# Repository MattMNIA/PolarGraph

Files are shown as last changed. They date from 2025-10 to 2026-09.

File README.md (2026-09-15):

# PHINEAS

**P**lotting **H**ardware for **I**nteractive **N**otation, **E**rasing, **A**nd **S**ketching — a
belt-driven polargraph that draws on a standard classroom whiteboard. Drop an image into the
browser, place it on a scale drawing of your board, and the machine draws it with a dry-erase
marker.

<p align="center">
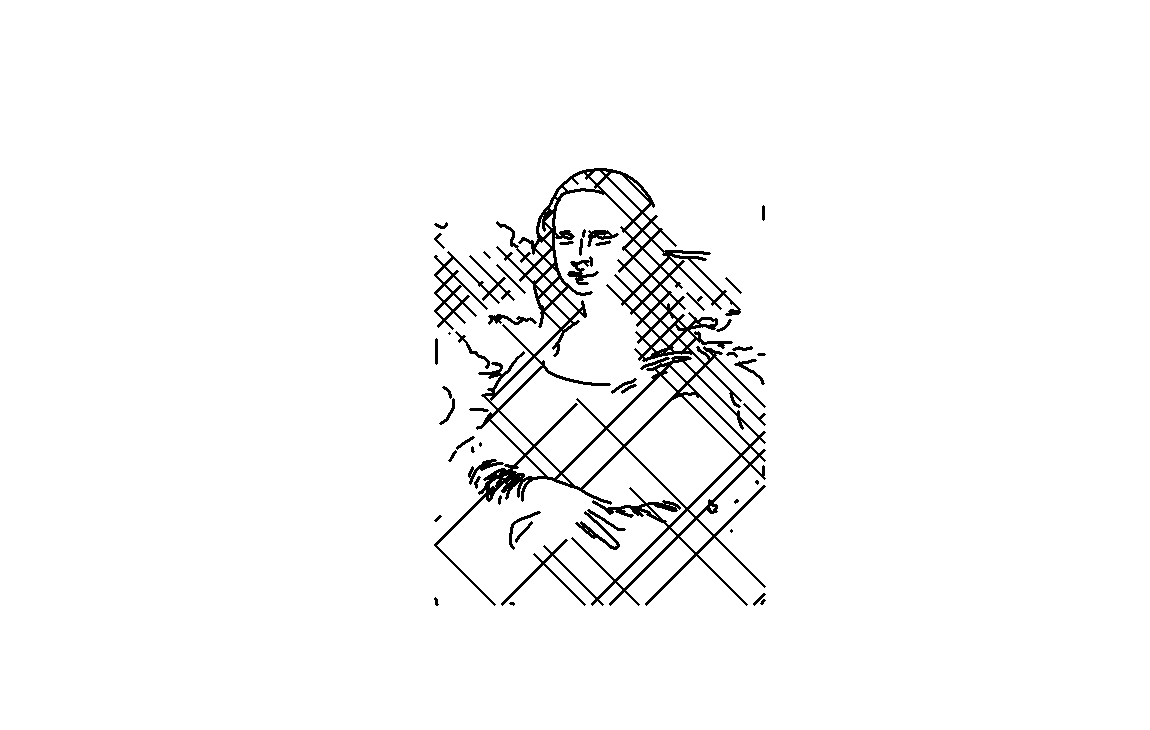
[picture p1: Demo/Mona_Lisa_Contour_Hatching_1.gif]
Simulated pen path for a contour + hatch render of the Mona Lisa
  
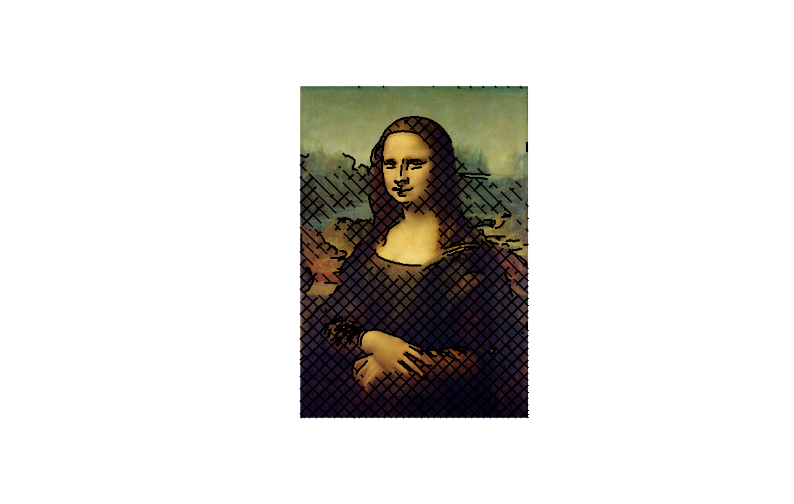
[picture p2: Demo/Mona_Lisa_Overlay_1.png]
Finished drawing on the whiteboard
  
</p>

A gondola hangs from two GT2 belts driven by stepper motors in the top corners of the board. Its
position is set entirely by the two belt lengths, so moving the pen means solving for those two
lengths and stepping both motors together. A hobby servo on the gondola lifts the marker off the
board between strokes.

## How it works

```
image ──▶ OpenCV                ──▶ path planner            ──▶ Flask API ──▶ ESP32 ──▶ steppers
          contours / hatching       ordering, pen-up/down        batches       inverse    + pen servo
          /  dark fill              interpolation, merging       of 200 pts    kinematics
```

1. **Trace.** `polargraph/image_processing.py` reduces the image to pen strokes, in one of three
   modes: `contour` (edge outlines with centerline extraction), `hatch` (outlines plus angled
   hatching whose density follows image brightness), or `fill` (outlines plus solid fill of dark
   regions).
2. **Plan.** `polargraph/path_planner.py` splits and merges contours where they nearly touch,
   orders them nearest-neighbour to cut travel, then interpolates every stroke to a fixed step
   size and marks each point pen-up or pen-down.
3. **Preview.** The React client renders the planned path over a scale drawing of the board, so
   you can see the result and the estimated draw time before committing a marker to it.
4. **Stream.** `polargraph/path_sender.py` pushes the path to the ESP32 in 200-point batches on a
   background thread, keeping the controller's queue full without blocking the API. Progress,
   pause, resume, and cancel are all polled over HTTP.
5. **Draw.** The firmware converts each point to a pair of belt lengths, steps both motors in
   coordinated fashion, and drives the pen servo. It parks the gondola when the job finishes.

## Layout

| Path | What's in it |
|---|---|
| `client/` | React + Tailwind front end: board layout editor, drawing-method controls, live job monitor, motor jog/test pages. |
| `visualization/` | Flask API and the `polargraph` Python package — kinematics, image processing, path planning, and the batched path sender. |
| `visualization/examples/` | Standalone scripts: shapes, calibration squares, timing tests, a diagnostic suite. |
| `visualization/tests/` | Unit tests for the kinematics and path planning. |
| `firmware/` | ESP32 Arduino sketch (WebServer + TMCStepper + ESP32Servo) and two PowerShell helpers for poking the controller by hand. |
| `Demo/` | Sample output. |

CAD (`.3mf` printable parts), the KiCad project for the driver board, and the bill of materials
live outside the repo — ask if you want them.

## Running it

**Backend** (Python 3.8+):

```bash
cd visualization
python -m venv .venv && .venv/Scripts/activate   # source .venv/bin/activate on macOS/Linux
pip install -r requirements.txt
python app.py                                    # serves on :8001
```

**Front end** (Node 18+):

```bash
cd client
npm install
npm start                                        # dev server on :3000, talking to the API on :8001
```

`npm run build` emits into `client/build/`, which `app.py` serves directly — so a production run is
just the Flask process.

**Firmware** (Arduino IDE or `arduino-cli`, ESP32 board support installed):

1. Copy `firmware/polargraph_firmware/secrets.example.h` to `secrets.h` in the same folder and fill
   in your WiFi credentials. That file is gitignored.
2. Check the machine geometry constants at the top of `polargraph_firmware.ino` —
   `BOARD_WIDTH_MM`, `BOARD_HEIGHT_MM`, `SPOOL_DIAMETER_MM`, `MICROSTEPS`, and the pen servo
   angles all have to match your build.
3. Flash it. The sketch prints its IP on the serial console; paste that into the client's
   controller URL field.

Libraries used by the sketch: `ArduinoJson`, `TMCStepper`, `ESP32Servo`.

## API

Flask (`visualization/app.py`):

| Endpoint | Purpose |
|---|---|
| `POST /api/visualize` | Plan a drawing from a board layout; returns the preview, path stats, and optionally starts streaming. |
| `POST /api/animation` | Render an animated preview of the planned path. |
| `POST /api/send-path` | Queue a path for transmission; returns a job id immediately. |
| `GET /api/send-path/status` | Poll progress, totals, and errors for the active job. |
| `POST /api/send-path/{cancel,pause,resume}` | Control the in-flight job. |
| `GET,POST /api/controller/status` | Read the cached ESP32 status, or point the poller at a controller. |

ESP32 (`firmware/polargraph_firmware/`):

| Endpoint | Purpose |
|---|---|
| `GET /api/status` | Position, queue depth, pen state, job flags. |
| `POST /api/move` | Move to an absolute coordinate. |
| `POST /api/pen` | Raise or lower the pen. |
| `POST /api/path` | Enqueue a batch of points. |
| `POST /api/cancel` | Stop and flush the queue. |
| `POST /api/park` | Return the gondola to its parking position. |

## Machine

| | |
|---|---|
| Controller | ESP32-S dev board (WiFi, HTTP server, FreeRTOS task for motion) |
| Motors | 2 × NEMA 17 (1.5 A, 42 Ncm), TMC2209 drivers addressed over UART, 32 microsteps |
| Motion | GT2 belt on 12 mm spools, ≈170 steps/mm, 6000 steps/s ceiling |
| Pen | Hobby servo on the gondola, 45° up / 105° down |
| Board | 1150 × 730 mm drawing area as configured |

## Tests

```bash
cd visualization
pip install pytest
python -m pytest tests
```

## License

MIT — see [LICENSE](LICENSE).

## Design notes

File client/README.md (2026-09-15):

# Client

React front end for the PHINEAS whiteboard plotter. See the [root README](../README.md) for the
project overview and setup.

## Screens

| Screen | File | What it does |
|---|---|---|
| Whiteboard | `src/components/Whiteboard.js` | The main workspace: drop in images or text, drag and resize them on a scale drawing of the board, pick a drawing method, preview the planned pen path, and start the job. |
| Motor control | `src/components/MotorControlPage.js` | Live job monitor — progress, pause/resume/cancel, pen and park controls. |
| Motor test | `src/components/MotorTestPage.js` | Jog each motor and exercise the pen servo directly. Hidden unless `REACT_APP_SHOW_MOTOR_TEST=true`. |

## Scripts

```bash
npm start     # dev server on :3000
npm run build # production bundle into build/, served by the Flask app
npm test      # react-scripts test runner
```

## Configuration

Create `client/.env` (gitignored) to override defaults:

| Variable | Default | Effect |
|---|---|---|
| `REACT_APP_API_BASE_URL` | `http://localhost:8001` in dev, same-origin in production | Where the Flask API lives. |
| `REACT_APP_PORT` | `8001` | API port, when the base URL isn't set outright. |
| `REACT_APP_SHOW_MOTOR_TEST` | unset | Set to `true` to expose the motor test screen. |

The UI system — tokens, primitives, and the rules that keep them consistent — is documented in
[THEME_README.md](THEME_README.md).

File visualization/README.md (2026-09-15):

# Backend

Flask API and the `polargraph` package behind PHINEAS. See the [root README](../README.md) for the
project overview and setup.

## Package

| Module | Role |
|---|---|
| `polargraph/kinematics.py` | The geometry: belt lengths for an (x, y) pen position, and the inverse. |
| `polargraph/image_processing.py` | Image → pen strokes. `image_to_contour_paths`, `image_to_hatch_paths`, `image_to_dark_fill_paths`, plus the hatch-line generator and path smoothing. |
| `polargraph/path_planner.py` | Stroke ordering and interpolation: split and merge contours at near-touches, nearest-neighbour ordering, fixed-step interpolation, pen-up/down marking. |
| `polargraph/path_sender.py` | Batched, non-blocking transmission to the ESP32 with progress, pause, resume, and cancel. |
| `polargraph/whiteboard_manager.py` | Multi-image board layout: placement, bounds checking, composite rendering. |
| `polargraph/plot.py` | Matplotlib preview and animation of the pen and belts. |

## Running

```bash
python -m venv .venv && .venv/Scripts/activate   # source .venv/bin/activate on macOS/Linux
pip install -r requirements.txt
python app.py                                    # :8001, or set PORT
```

`app.py` also serves `../client/build/` at `/`, so once the front end is built the Flask process is
the whole application.

## Endpoints

| Endpoint | Purpose |
|---|---|
| `POST /api/visualize` | Plan a drawing from a board layout; returns preview images and path stats. Pass `sendToController: true` (with `controllerUrl`) to start streaming at the same time. |
| `POST /api/animation` | Render an animated preview of the planned path. |
| `POST /api/send-path` | Queue a path for transmission. Takes `controllerUrl`, `path` (a list of `{x, y, penDown}`), and optional `speed`, `reset`, `startPosition`. Returns a job id immediately; a background worker handles the batches. |
| `GET /api/send-path/status` | Poll the active or most recent job — progress, totals, errors. |
| `POST /api/send-path/cancel` | Cancel the in-flight job. |
| `POST /api/send-path/pause`, `/resume` | Hold and release the in-flight job. |
| `GET /api/controller/status` | Read the cached ESP32 status (a background poller keeps it fresh). |
| `POST /api/controller/status` | Point the poller at a controller URL. |

## Scripts

```bash
# Plan a drawing from the command line
python examples/run_simulation.py --images images/mona_lisa.jpg --method hatch --board-width 900 --board-height 550

# Hardware shakedown: shapes, a calibration square, a centered circle, timing
python examples/draw_square_calibration.py
python examples/diagnostic_suite.py

# Interactive multi-image layout
python layout_tool.py
```

`run_simulation.py` takes `--images`, `--positions` (`x,y,width,height` per image), `--board-width`,
`--board-height`, `--step-mm`, `--method` (`contour` or `hatch`), and `--spacing`.

## Tests

```bash
pip install pytest
python -m pytest tests
```

## Notes

- Contour extraction needs `opencv-python`; the image processing module raises a clear error if it
  isn't installed.
- `visualization/images/` holds the test images used while developing the tracing modes.

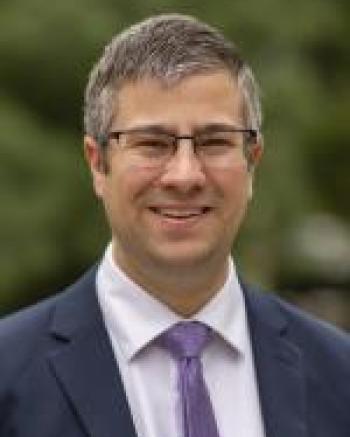
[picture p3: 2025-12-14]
visualization/images/javanshields-headshot_2.jpeg

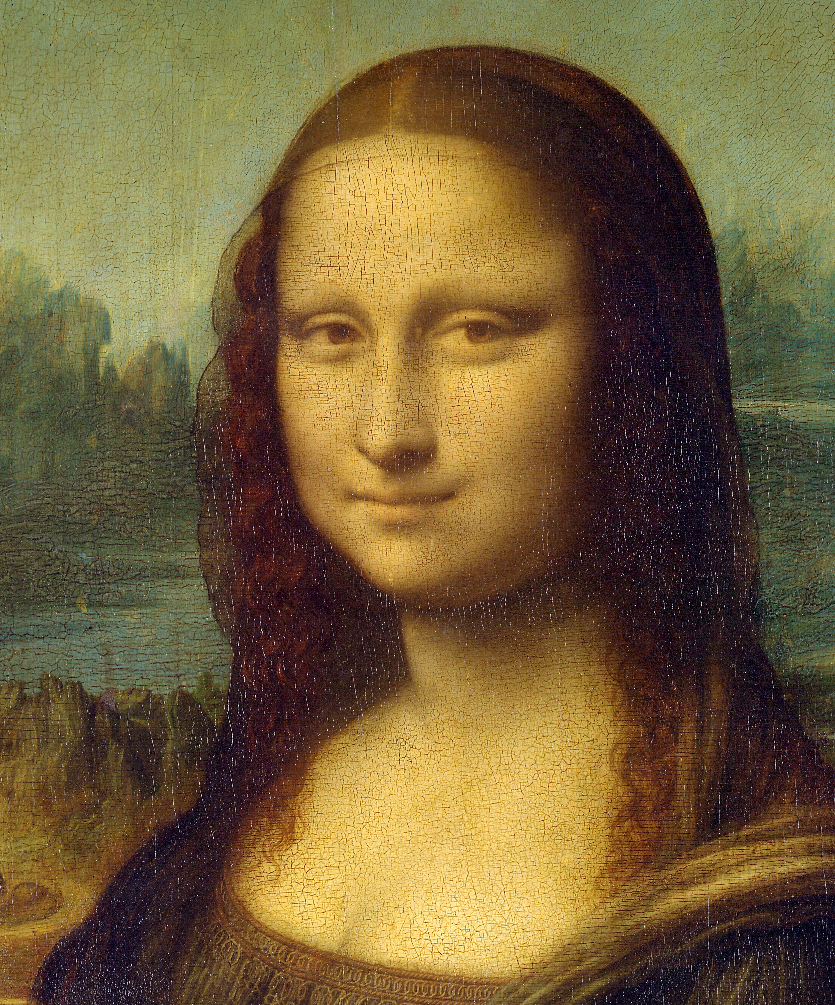
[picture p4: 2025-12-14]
visualization/images/mona_lisa_face.jpg

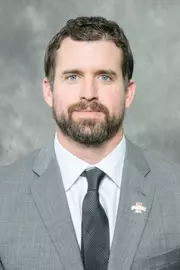
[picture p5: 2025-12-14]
visualization/images/Jimmy_Rogers.webp

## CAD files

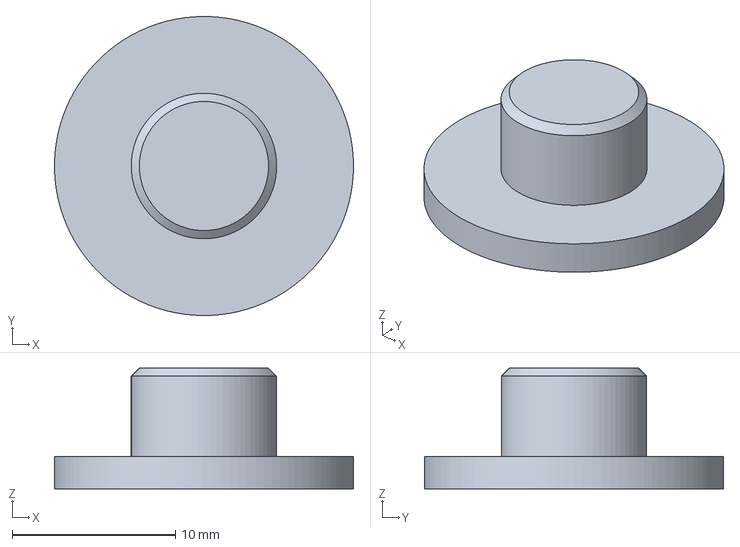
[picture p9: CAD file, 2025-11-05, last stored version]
CAD/Marker Holder.3mf
18.3 x 18.3 x 7.40 mm

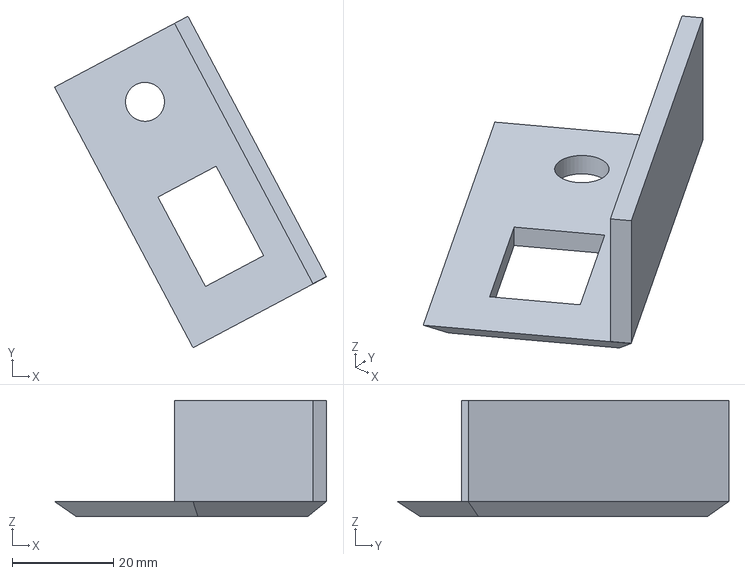
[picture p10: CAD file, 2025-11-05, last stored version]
CAD/Switch and Female Holder.3mf
53.7 x 65.5 x 23.0 mm

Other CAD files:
CAD/Marker Holder.stl
CAD/Switch and Female Holder.stl

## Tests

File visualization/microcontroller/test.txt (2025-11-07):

curl.exe -X POST http://192.168.50.5/api/path `
  -H "Content-Type: application/json" `
  -d '{
  "reset": true,
  "speed": 1800,
  "startPosition": { "x": 220, "y": 180 },
  "points": [
    { "x": 220, "y": 180, "penDown": false },
    { "x": 260, "y": 220, "penDown": false },
    { "x": 260, "y": 220, "penDown": true },
    { "x": 410, "y": 220, "penDown": true },
    { "x": 410, "y": 370, "penDown": true },
    { "x": 260, "y": 370, "penDown": true },
    { "x": 260, "y": 220, "penDown": true },
    { "x": 260, "y": 220, "penDown": false },
    { "x": 440, "y": 200, "penDown": false },
    { "x": 440, "y": 200, "penDown": true },
    { "x": 500, "y": 270, "penDown": true },
    { "x": 560, "y": 220, "penDown": true },
    { "x": 560, "y": 220, "penDown": false }
  ]
}'

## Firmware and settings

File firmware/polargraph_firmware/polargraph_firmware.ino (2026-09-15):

#include <WiFi.h>
#include <WebServer.h>
#include <ArduinoJson.h>
#include <TMCStepper.h>
#include <ESP32Servo.h>
#include <math.h>
#include <limits.h>
#include <deque>
#include <freertos/FreeRTOS.h>
#include <freertos/semphr.h>

#include "secrets.h"

constexpr float R_SENSE = 0.11f;

constexpr uint8_t DRIVER_ADDR_LEFT = 0b00;
constexpr uint8_t DRIVER_ADDR_RIGHT = 0b01;

// SAFETY/SMOOTHNESS TWEAKS
constexpr uint32_t DEFAULT_SPEED = 5000;     
constexpr uint32_t TRAVEL_SPEED = 6000;    // Faster speed for pen-up moves
constexpr uint16_t DEFAULT_CURRENT = 800;  
constexpr uint32_t MAX_SPEED = 6000;       // Increased max speed
constexpr uint8_t MIN_PULSE_US = 10;        // Reduced min pulse for higher speeds
constexpr uint16_t MAX_QUEUE_SIZE = 3000;   

// MACHINE GEOMETRY & RESOLUTION
constexpr float BOARD_WIDTH_MM = 1150.0f;
constexpr float BOARD_HEIGHT_MM = 730.0f;
constexpr float CONNECTION_TO_PEN_DISTANCE = 29.0f;
constexpr float MOTOR_OFFSET_Y = 60.0f;
constexpr float DEFAULT_START_X = 575.0f;  // Physical home X
constexpr float DEFAULT_START_Y = 365.0f;  // Physical home Y
constexpr uint16_t STEPS_PER_REV = 200;
constexpr uint8_t MICROSTEPS = 32;        
constexpr float SPOOL_DIAMETER_MM = 12.0f;
constexpr float SPOOL_CIRCUMFERENCE_MM = SPOOL_DIAMETER_MM * PI;
constexpr float STEPS_PER_MM = (STEPS_PER_REV * MICROSTEPS) / SPOOL_CIRCUMFERENCE_MM;

// PEN SERVO
constexpr int PEN_SERVO_PIN = 15;
constexpr int PEN_UP_ANGLE = 45;      
constexpr int PEN_DOWN_ANGLE = 105;   
constexpr uint16_t PEN_SERVO_SETTLE_MS = 400;

struct MachineState {
    float x_mm;
    float y_mm;
    float left_len_mm;
    float right_len_mm;
    int64_t left_steps;
    int64_t right_steps;
    bool pen_down;
    bool initialized;
};

struct QueuedPoint {
    float l1;
    float l2;
    bool penDown;
    uint32_t speed;
};

struct MotorConfig {
    const char* id;
    uint8_t enablePin;
    uint8_t dirPin;
    uint8_t stepPin;
    TMC2209Stepper* driver;
    volatile bool busy;
};

// Hardware Serial (UART2) for TMC communication
HardwareSerial driverSerial(2);  
TMC2209Stepper driverLeft(&driverSerial, R_SENSE, DRIVER_ADDR_LEFT);
TMC2209Stepper driverRight(&driverSerial, R_SENSE, DRIVER_ADDR_RIGHT);

MotorConfig motors[] = {
  {"left", 21, 5, 4, &driverLeft, false},    // EN=21, DIR=5, STEP=4
  {"right", 19, 22, 23, &driverRight, false} // EN=19, DIR=22, STEP=23
};


WebServer server(80);

MachineState machine = {BOARD_WIDTH_MM/2, BOARD_HEIGHT_MM/2, 0.0f, 0.0f, 0, 0, false, false};

std::deque<QueuedPoint> pointQueue;
volatile bool isExecuting = false;
bool endOfJobReceived = false;
SemaphoreHandle_t queueMutex = nullptr;
SemaphoreHandle_t stateMutex = nullptr;

static inline void lockQueue() {
    if (queueMutex) {
        xSemaphoreTake(queueMutex, portMAX_DELAY);
    }
}

static inline void unlockQueue() {
    if (queueMutex) {
        xSemaphoreGive(queueMutex);
    }
}

static inline void lockState() {
    if (stateMutex) {
        xSemaphoreTake(stateMutex, portMAX_DELAY);
    }
}

static inline void unlockState() {
    if (stateMutex) {
        xSemaphoreGive(stateMutex);
    }
}

Servo penServo;
bool servoPenDown = false;
volatile bool cancelRequested = false;

void applyPenState(bool down);

// Forward declaration
bool computeStringLengths(float x, float y, float& leftLen, float& rightLen);

// Forward Kinematics: Calculate X/Y from string lengths
bool computeXYFromLengths(float l1, float l2, float &x, float &y) {
    float d = CONNECTION_TO_PEN_DISTANCE;
    float h = MOTOR_OFFSET_Y;
    float W = BOARD_WIDTH_MM;
    float W_prime = W - d;
    
    // Derived from:
    // L1^2 = (x-d)^2 + (y+h)^2
    // L2^2 = (W-(x+d))^2 + (y+h)^2
    // Solving for x:
    float denominator = 2.0f * (d - W_prime);
    if (abs(denominator) < 0.001f) return false;

    float numerator = (l2 * l2) - (l1 * l1) + (d * d) - (W_prime * W_prime);
    x = numerator / denominator;

    // Solving for y:
    float term = (l1 * l1) - ((x - d) * (x - d));
    if (term < 0) return false;
    
    y = sqrt(term) - h;
    return true;
}

// Utility to set machine state to a known absolute position (used only at cold boot default).
bool setMachineState(float x, float y, bool penDown) {
    float leftLen = 0.0f;
    float rightLen = 0.0f;
    if (!computeStringLengths(x, y, leftLen, rightLen)) {
        return false;
    }

    lockState();
    machine.x_mm = x;
    machine.y_mm = y;
    machine.left_len_mm = leftLen;
    machine.right_len_mm = rightLen;
    machine.left_steps = llround(static_cast<double>(leftLen) * STEPS_PER_MM);
    machine.right_steps = llround(static_cast<double>(rightLen) * STEPS_PER_MM);
    machine.pen_down = penDown;
    machine.initialized = true;
    unlockState();
    
    applyPenState(penDown);
    return true;
}

// Overload for setting state directly from lengths
bool setMachineStateLengths(float l1, float l2, bool penDown) {
    float x = 0.0f;
    float y = 0.0f;
    computeXYFromLengths(l1, l2, x, y); // Best effort to update X/Y for status

    lockState();
    machine.x_mm = x;
    machine.y_mm = y;
    machine.left_len_mm = l1;
    machine.right_len_mm = l2;
    machine.left_steps = llround(static_cast<double>(l1) * STEPS_PER_MM);
    machine.right_steps = llround(static_cast<double>(l2) * STEPS_PER_MM);
    machine.pen_down = penDown;
    machine.initialized = true;
    unlockState();

    applyPenState(penDown);
    return true;
}


void emergencyStop() {
    for (auto& motor : motors) {
        enableMotor(motor, false);
        motor.busy = false;
    }
    applyPenState(false);
    machine.pen_down = false;
}

void addCorsHeaders() {
    server.sendHeader("Access-Control-Allow-Origin", "*");
    server.sendHeader("Access-Control-Allow-Headers", "Content-Type");
    server.sendHeader("Access-Control-Allow-Methods", "GET,POST,OPTIONS");
}

void handleCorsPreflight() {
    addCorsHeaders();
    server.send(204);
}

MotorConfig* findMotor(const char* id) {
    for (auto& motor : motors) {
        if (strcmp(motor.id, id) == 0) {
            return &motor;
        }
    }
    return nullptr;
}

uint32_t clampSpeed(uint32_t speed) {
    if (speed == 0) {
        speed = DEFAULT_SPEED;
    }
    return min(speed, MAX_SPEED);
}

void setupDriver(TMC2209Stepper& driver) {
    driver.begin();
    driver.toff(5);
    driver.rms_current(DEFAULT_CURRENT);
    driver.en_spreadCycle(false);
    driver.pdn_disable(true);
    driver.microsteps(MICROSTEPS);
    driver.I_scale_analog(false);
}

void enableMotor(MotorConfig& motor, bool enable) {
    digitalWrite(motor.enablePin, enable ? LOW : HIGH);
}

void performSteps(MotorConfig& motor, int32_t steps, uint32_t speed) {
    motor.busy = true;

    const bool forward = steps > 0;
    const uint32_t totalSteps = static_cast<uint32_t>(abs(steps));
    const uint32_t targetSpeed = clampSpeed(speed);
    const uint32_t stepDelayUs = max(1000000UL / targetSpeed, static_cast<uint32_t>(MIN_PULSE_US * 4));

    enableMotor(motor, true);
    digitalWrite(motor.dirPin, forward ? HIGH : LOW);

    for (uint32_t i = 0; i < totalSteps; ++i) {
        if (cancelRequested) {
            enableMotor(motor, false);
            motor.busy = false;
            return;
        }
        digitalWrite(motor.stepPin, HIGH);
        delayMicroseconds(MIN_PULSE_US);
        digitalWrite(motor.stepPin, LOW);
        delayMicroseconds(stepDelayUs - MIN_PULSE_US);
        
        if (i % 100 == 0) {
            yield();
        }
    }

    motor.busy = false;
}

void pulsePin(uint8_t pin) {
    digitalWrite(pin, HIGH);
    delayMicroseconds(MIN_PULSE_US);
    digitalWrite(pin, LOW);
}

bool runDualMotorSteps(int32_t leftDelta, int32_t rightDelta, uint32_t speed) {
    MotorConfig& left = motors[0];
    MotorConfig& right = motors[1];

    const uint32_t leftSteps = static_cast<uint32_t>(abs(leftDelta));
    const uint32_t rightSteps = static_cast<uint32_t>(abs(rightDelta));
    const uint32_t maxSteps = max(leftSteps, rightSteps);
    if (maxSteps == 0) return true;

    const uint32_t targetSpeed = clampSpeed(speed);
    const uint32_t stepDelayUs = max(1000000UL / targetSpeed, static_cast<uint32_t>(MIN_PULSE_US * 4));

    left.busy = true;
    right.busy = true;

    enableMotor(left, true);
    enableMotor(right, true);

    digitalWrite(left.dirPin, leftDelta >= 0 ? LOW : HIGH);
    digitalWrite(right.dirPin, rightDelta >= 0 ? LOW : HIGH);

    uint32_t accLeft = 0;
    uint32_t accRight = 0;

    for (uint32_t i = 0; i < maxSteps; ++i) {
        if (cancelRequested) {
            emergencyStop();
            left.busy = false;
            right.busy = false;
            return false;
        }

        accLeft += leftSteps;
        accRight += rightSteps;

        if (accLeft >= maxSteps) {
            accLeft -= maxSteps;
            pulsePin(left.stepPin);
        }
        if (accRight >= maxSteps) {
            accRight -= maxSteps;
            pulsePin(right.stepPin);
        }

        delayMicroseconds(stepDelayUs);
        
        // Feed watchdog and handle network periodically to prevent timeouts and improve step timing
        if (i % 100 == 0) {
            yield();
        }
    }

    left.busy = false;
    right.busy = false;

    if (cancelRequested) {
        emergencyStop();
        return false;
    }

    return true;
}

void applyPenState(bool down) {
    if (!penServo.attached()) return;
    if (servoPenDown == down) return;

    const int angle = down ? PEN_DOWN_ANGLE : PEN_UP_ANGLE;
    penServo.write(angle);
    delay(PEN_SERVO_SETTLE_MS);
    servoPenDown = down;
}

bool computeStringLengths(float x, float y, float& leftLen, float& rightLen) {
    if (x < 0 || y < 0) return false;

    float leftConnection_x = x - CONNECTION_TO_PEN_DISTANCE;
    float rightConnection_x = x + CONNECTION_TO_PEN_DISTANCE;

    float motor_relative_y = y + MOTOR_OFFSET_Y;

    leftLen = sqrtf(leftConnection_x * leftConnection_x + motor_relative_y * motor_relative_y);
    float dx = BOARD_WIDTH_MM - rightConnection_x;
    rightLen = sqrtf(dx * dx + motor_relative_y * motor_relative_y);

    if (!(isfinite(leftLen) && isfinite(rightLen))) return false;
    return true;
}

bool moveToLengths(float l1, float l2, bool penDown, uint32_t speed) {
    if (!isfinite(l1) || !isfinite(l2)) {
        Serial.println("[MOVE] Invalid target lengths");
        return false;
    }

    const int64_t targetLeftSteps = llround(static_cast<double>(l1) * static_cast<double>(STEPS_PER_MM));
    const int64_t targetRightSteps = llround(static_cast<double>(l2) * static_cast<double>(STEPS_PER_MM));

    const int64_t leftDelta = targetLeftSteps - machine.left_steps;
    const int64_t rightDelta = targetRightSteps - machine.right_steps;

    if (llabs(leftDelta) > INT32_MAX || llabs(rightDelta) > INT32_MAX) {
        Serial.printf("[MOVE] Delta overflow left=%lld right=%lld\n", static_cast<long long>(leftDelta), static_cast<long long>(rightDelta));
        return false;
    }

    static uint32_t moveLogCounter = 0;
    moveLogCounter++;
    if (moveLogCounter <= 5 || moveLogCounter % 500 == 0) {
        Serial.printf("[MOVE] target=(L1:%.2f, L2:%.2f) pen=%s speed=%lu | leftDelta=%ld rightDelta=%ld\n",
            l1, l2, penDown ? "down" : "up", static_cast<unsigned long>(speed),
            static_cast<long>(leftDelta), static_cast<long>(rightDelta));
    }

    applyPenState(penDown);

    // If pen is UP, use a faster travel speed unless a specific speed was requested that is higher
    uint32_t effectiveSpeed = speed;
    if (!penDown) {
        effectiveSpeed = max(speed, TRAVEL_SPEED);
    }

    if (!runDualMotorSteps(static_cast<int32_t>(leftDelta), static_cast<int32_t>(rightDelta), effectiveSpeed)) {
        return false;
    }

    lockState();
    machine.left_steps = targetLeftSteps;
    machine.right_steps = targetRightSteps;
    machine.left_len_mm = l1;
    machine.right_len_mm = l2;
    
    // Update X/Y for status reporting
    computeXYFromLengths(l1, l2, machine.x_mm, machine.y_mm);
    
    machine.pen_down = penDown;
    unlockState();

    return true;
}

// ---------- Server Handlers ----------

void handleMove() {
    addCorsHeaders();
    if (server.method() != HTTP_POST) {
        server.send(405, "application/json", "{\"error\":\"Use POST\"}");
        return;
    }

    if (!server.hasArg("plain")) {
        server.send(400, "application/json", "{\"error\":\"Missing body\"}");
        return;
    }

    StaticJsonDocument<256> doc;
    const DeserializationError err = deserializeJson(doc, server.arg("plain"));
    if (err) {
        server.send(400, "application/json", "{\"error\":\"Bad JSON\"}");
        return;
    }

    const char* motorId = doc["motor"] | "left";
    const int32_t steps = doc["steps"] | 0;
    const uint32_t speed = doc["speed"] | DEFAULT_SPEED;

    MotorConfig* motor = findMotor(motorId);
    if (!motor) {
        server.send(404, "application/json", "{\"error\":\"Unknown motor\"}");
        return;
    }

    if (motor->busy) {
        server.send(409, "application/json", "{\"error\":\"Motor busy\"}");
        return;
    }

    if (steps == 0) {
        server.send(200, "application/json", "{\"status\":\"noop\"}");
        return;
    }

    performSteps(*motor, steps, speed);

    StaticJsonDocument<128> response;
    response["status"] = "ok";
    response["motor"] = motorId;
    response["steps"] = steps;
    response["speed"] = clampSpeed(speed);

    String payload;
    serializeJson(response, payload);
    server.send(200, "application/json", payload);
}

void handleStatus() {
    addCorsHeaders();
    StaticJsonDocument<512> doc;
    doc["wifi"]["ip"] = WiFi.localIP().toString();

    JsonArray motorsArray = doc.createNestedArray("motors");
    for (auto& motor : motors) {
        JsonObject entry = motorsArray.createNestedObject();
        entry["id"] = motor.id;
        entry["busy"] = motor.busy;
    }

    lockState();
    JsonObject state = doc.createNestedObject("state");
    state["initialized"] = machine.initialized;
    state["x_mm"] = machine.x_mm;
    state["y_mm"] = machine.y_mm;
    state["penDown"] = machine.pen_down;

    JsonObject lengths = state.createNestedObject("lengths_mm");
    lengths["left"] = machine.left_len_mm;
    lengths["right"] = machine.right_len_mm;

    JsonObject steps = state.createNestedObject("steps");
    steps["left"] = machine.left_steps;
    steps["right"] = machine.right_steps;
    unlockState();

    size_t queueSizeSnapshot = 0;
    bool executingSnapshot = false;
    lockQueue();
    queueSizeSnapshot = pointQueue.size();
    executingSnapshot = isExecuting;
    unlockQueue();

    JsonObject queueInfo = doc.createNestedObject("queue");
    queueInfo["size"] = queueSizeSnapshot;
    queueInfo["isExecuting"] = executingSnapshot;

    String payload;
    serializeJson(doc, payload);
    server.send(200, "application/json", payload);
}

void handleRoot() {
    addCorsHeaders();
    server.send(200, "text/plain", "ESP32 motion controller online (Length-based).");
}

void handlePen() {
    addCorsHeaders();
    if (server.method() != HTTP_POST) {
        server.send(405, "application/json", "{\"error\":\"Use POST\"}");
        return;
    }

    if (!server.hasArg("plain")) {
        server.send(400, "application/json", "{\"error\":\"Missing body\"}");
        return;
    }

    StaticJsonDocument<128> doc;
    const DeserializationError err = deserializeJson(doc, server.arg("plain"));
    if (err) {
        server.send(400, "application/json", "{\"error\":\"Bad JSON\"}");
        return;
    }

    const bool penDown = doc["penDown"] | false;
    applyPenState(penDown);
    machine.pen_down = penDown;

    StaticJsonDocument<128> response;
    response["status"] = "ok";
    response["penDown"] = penDown;

    String payload;
    serializeJson(response, payload);
    server.send(200, "application/json", payload);
}

void handleCancel() {
    addCorsHeaders();
    if (server.method() != HTTP_POST) {
        server.send(405, "application/json", "{\"error\":\"Use POST\"}");
        return;
    }

    cancelRequested = true;
    emergencyStop();

    lockQueue();
    pointQueue.clear();
    isExecuting = false;
    endOfJobReceived = false;
    unlockQueue();

    StaticJsonDocument<128> response;
    response["status"] = "ok";
    response["cancelled"] = true;
    response["queueCleared"] = true;

    String payload;
    serializeJson(response, payload);
    server.send(200, "application/json", payload);
}
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
void loop() {
    // server.handleClient(); // Moved to serverTask

    QueuedPoint point;
    bool hasPoint = false;

    lockQueue();
    if (isExecuting && !pointQueue.empty()) {
        point = pointQueue.front();
        pointQueue.pop_front();
        hasPoint = true;
    }
    unlockQueue();

    if (!hasPoint) return;

    // Throttle logging to avoid slowing down high-resolution paths
    static uint32_t loopLogCounter = 0;
    loopLogCounter++;
    if (loopLogCounter % 100 == 0) {
        Serial.printf("[QUEUE] Executing queued point -> (L1:%.2f, L2:%.2f) pen=%s speed=%lu\n",
            point.l1, point.l2, point.penDown ? "down" : "up", static_cast<unsigned long>(point.speed));
    }

    if (!moveToLengths(point.l1, point.l2, point.penDown, point.speed)) {
        Serial.println(F("[QUEUE] moveToLengths failed, stopping execution"));
        lockQueue();
        isExecuting = false;
        pointQueue.clear();
        unlockQueue();
        return;
    }

    if (cancelRequested) {
        Serial.println(F("[QUEUE] Cancel detected, stopping execution"));
        cancelRequested = false;
        lockQueue();
        isExecuting = false;
        pointQueue.clear();
        unlockQueue();
        return;
    }

    bool queueEmpty = false;
    lockQueue();
    queueEmpty = pointQueue.empty();
    if (queueEmpty) {
        if (endOfJobReceived) {
            isExecuting = false;
            endOfJobReceived = false;
            Serial.println(F("[QUEUE] Queue empty and endOfJob received, execution complete"));
        }
    }
    unlockQueue();
}

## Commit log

2025-11-05 Enable drag and dropping images
    [Marker Holder.3mf, Marker Holder.stl, Switch and Female Holder.3mf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]
2025-11-05 Can move both motors independently
2025-11-07 Removed CAD files
    [Marker Holder.3mf, Marker Holder.stl, Switch and Female Holder.3mf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]
2025-11-08 Hide test motors button
2025-11-08 Add motor control page
2025-11-10 Add loading wheel if status check from frontend fails
2025-12-16 Add time estimate and calibrate vavlue
2025-12-17 fix job finish flag
    [firmware_l1l2.ino]
2025-12-17 Update board margin
2025-12-17 update board margins again
2025-12-18 Change compute and upload button to make it so they don't overlap
2026-01-28 Change default ESP32 URL
2026-09-15 Clean up repo for public release
    - Add a top-level README (PHINEAS), MIT LICENSE, and rewrite the client and
    backend READMEs; client/README.md was still Create React App boilerplate.
    - Move the firmware out of visualization/microcontroller into a top-level
    firmware/ with an Arduino-standard sketch folder. Drop current_code.ino in
    favour of the newer l1/l2 sketch.
    - Pull the WiFi credentials out of the firmware into a gitignored secrets.h,
    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
